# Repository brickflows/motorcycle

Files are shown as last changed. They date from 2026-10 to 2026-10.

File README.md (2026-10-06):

# Café Racer Concept

A complete motorcycle modelled part by part in SolidWorks, with my own bodywork and a frame I redesigned to pass structural analysis in ANSYS, then rendered and cut into a 70-second product film in Blender.

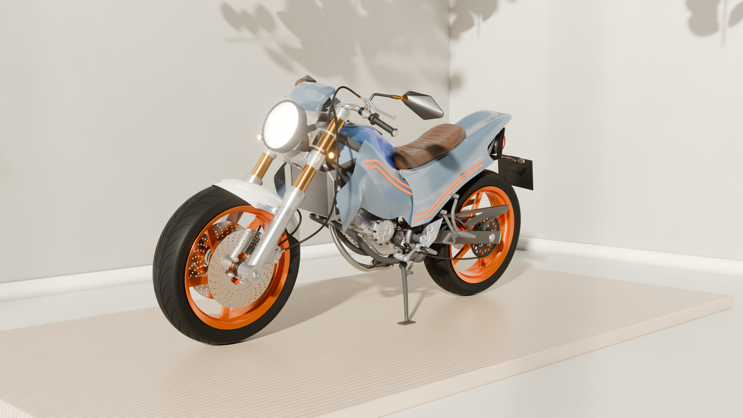
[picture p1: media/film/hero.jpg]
Café Racer Concept: watch the film


**[Watch the film (1080p, 23 MB)](media/film/cafe-racer-concept-1080p.mp4)** or on **[Watch on YouTube](https://www.youtube.com/watch?v=PtR7k8kXTPk)**

| | |
|---|---|
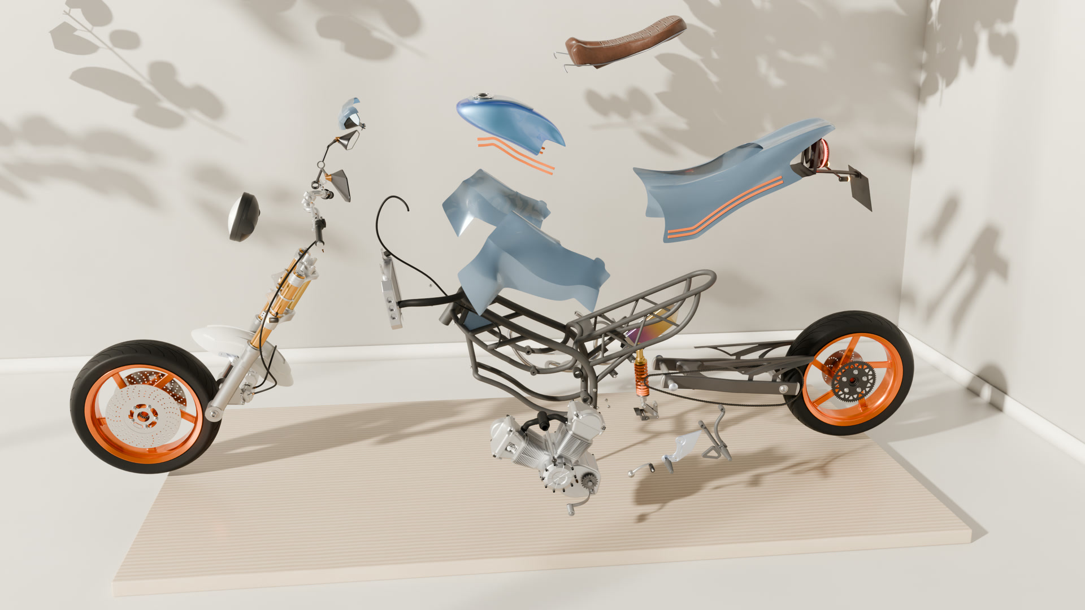
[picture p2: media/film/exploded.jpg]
Exploded view
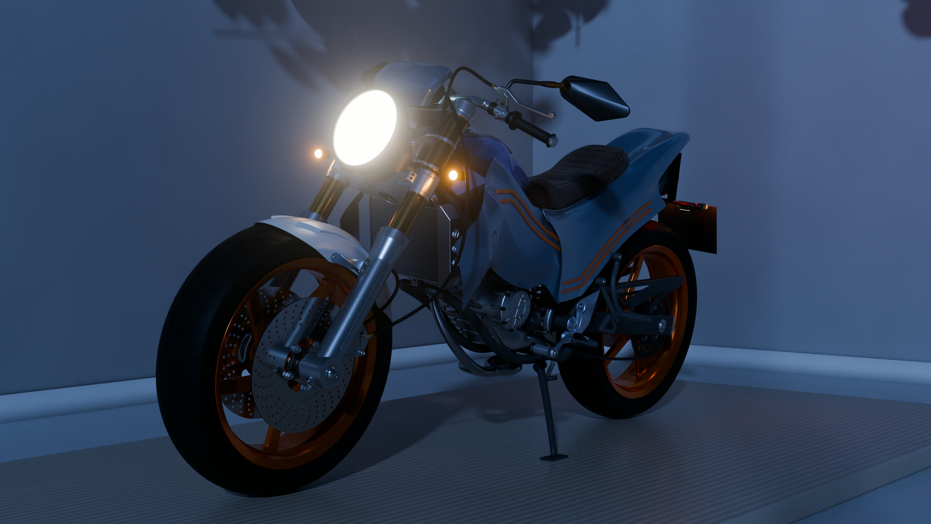
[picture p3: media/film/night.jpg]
Night scene with lights on
|  |  |
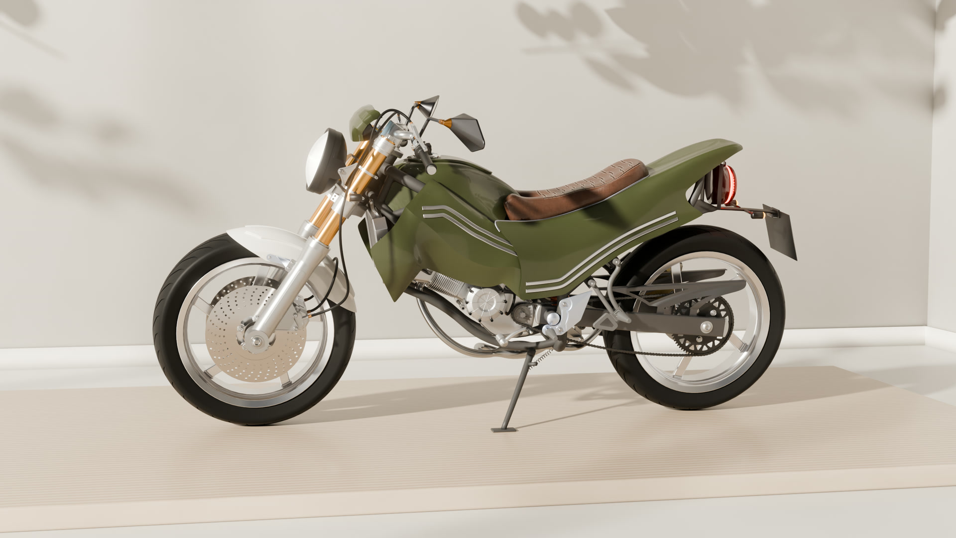
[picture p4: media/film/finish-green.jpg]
Army Green finish
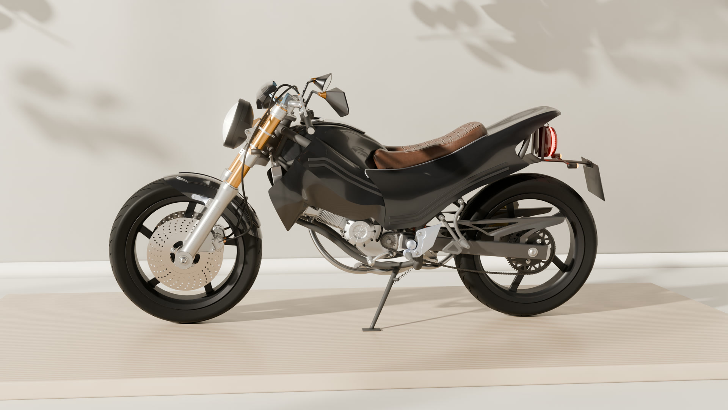
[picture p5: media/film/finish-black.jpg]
Midnight Black finish
|  |  |

## What is in this repo

| Folder | Contents |
|---|---|
| [`cad/`](cad) | SolidWorks source: 217 parts, 41 assemblies and 42 drawings, grouped by subsystem (engine cases, clutch hub, shafts, transmission, wheels, brakes, suspension, lights, bodywork). The top-level assembly is `cad/Assembly/motocycle_assembly1.SLDASM`. |
| [`cad/assembly drawings/`](cad/assembly%20drawings) | Assembly drawings as SolidWorks drawings and PDFs. |
| [`simulation/`](simulation) | Geometry used for the frame and output-shaft FEA, and the stress animations exported from ANSYS Mechanical. |
| [`media/renders/`](media/renders) | Stills of the sub-assemblies: engine, engine head, clutch hub, crankshaft, wheels, shock absorber, hand brake, mirrors, speedometer. |
| [`media/animations/`](media/animations) | The full assembly sequence from SolidWorks and a cam-chain motion study. |
| [`scripts/solidworks/`](scripts/solidworks) | VBA macros that assign materials across the assembly and export every sub-assembly to glTF for Blender. |
| [`scripts/film/`](scripts/film) | Python scripts that check and merge render-farm frames, add the captions and end card in Blender, and build the soundtrack. |
| [`docs/`](docs) | Proposed drawing-number scheme for the project. |

## How it was made

1. **CAD.** Every part was modelled in SolidWorks 2026 and built up through sub-assemblies into one top-level assembly. The bodywork (tank, seat, side and rear panels) is my own design.
2. **Simulation.** The frame was analysed in ANSYS Mechanical and redesigned until it passed. The output shaft was analysed as well.
3. **Export.** A macro walks the assembly tree and exports each sub-assembly to glTF, so the Blender scene keeps the same structure as the CAD.
4. **Rendering.** Materials, lighting and animation were done in Blender 5.2 with Cycles. The 1,620 frames were rendered at 2560x1440 on a render farm.
5. **Edit and sound.** Captions and the end card are added by `scripts/film/make_edit.py`. The soundtrack (music edit, engine and synthesized effects) is built and mastered by `scripts/film/make_audio.py`.

## Opening the CAD

Open `cad/Assembly/motocycle_assembly1.SLDASM` in SolidWorks 2026 or later. Keep the folder structure as it is so the assembly can find its parts.

## Not included

The Blender scene files, the raw ANSYS result files and the glTF exports are left out because of their size. The glTF exports can be regenerated with `scripts/solidworks/motorcycle_export_gltf.bas`.

## Credits

- The project started from the part reference drawings in Christopher Rothera's Udemy course "PTC Creo Parametric - Full Motorbike Build", which I remodelled in SolidWorks. The course material itself is not in this repo.
- The bodywork is my own design, the frame was redesigned to pass structural analysis, and a number of other parts were modified along the way.
- Music: "Hard EDM" by kulakovka, from Pixabay.
- Studio lighting: `studio_small_09` HDRI from Poly Haven. Several materials are from BlenderKit.

## Author

Micheal Adediran, Mechanical Engineering student at the University of Lagos. More work at [mikedoesrobots.com](https://mikedoesrobots.com).

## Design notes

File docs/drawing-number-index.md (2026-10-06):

# Motorcycle Build - Drawing Number Index (PROPOSED)

Generated 2026-09-03 from `C:\Users\micheal\Downloads\motorcyle`. **Planning pass only - nothing on disk was renamed or modified.**

- **192 documents**: 168 parts, 21 assemblies, 3 drawings

- **Scheme**: `MC-[TYPE]-[SEQ]`, SEQ zero-padded to 3 and incrementing per TYPE across the whole project, not per folder.

- **Sequencing basis**: file **creation date** (ascending), tie-broken alphabetically. See the caveat under *Sequencing* below.

- **Numbers are assigned to models.** A `.SLDDRW` inherits the number of the part or assembly it documents, so `foo.SLDPRT` and `foo.SLDDRW` share one DWG NO. rather than burning two.

## Type codes

Codes from your brief: `GER` `SFT` `HUB` `BRK` `PLT` `FRM`. `BRK` is unused - no bracket-type part appears in the project.

| Code | Meaning | Count |
|---|---|---|
| `ARM` | Arm | 11 |
| `ASM` | Assembly | 21 |
| `BAR` | Handlebar | 1 |
| `BAS` | Base | 1 |
| `BDG` | Bridge | 3 |
| `BDY` | Body | 4 |
| `BLB` | Bulb | 5 |
| `BLT` | Bolt / Screw | 17 |
| `BRG` | Bearing (incl. rings & balls) | 7 |
| `BSH` | Bushing | 3 |
| `CAP` | Cap | 2 |
| `CHN` | Chain Link | 4 |
| `CON` | Connector | 2 |
| `CSE` | Case / Housing | 12 |
| `DRM` | Drum | 1 |
| `FRM` | Frame Member | 7 |
| `GER` | Gear | 12 |
| `GRD` | Guard | 4 |
| `GRP` | Grip | 1 |
| `HUB` | Hub / Basket | 2 |
| `LNR` | Liner | 1 |
| `LVR` | Lever | 1 |
| `MAG` | Magnet | 1 |
| `MAN` | Manifold | 1 |
| `MIR` | Mirror | 1 |
| `MUF` | Muffler Section | 2 |
| `NUT` | Nut | 2 |
| `PIN` | Pin | 13 |
| `PIP` | Pipe | 3 |
| `PLG` | Plug | 4 |
| `PLT` | Plate | 7 |
| `PST` | Piston | 1 |
| `RAT` | Ratchet | 2 |
| `RIM` | Rim | 1 |
| `ROD` | Rod | 2 |
| `ROL` | Roller | 1 |
| `RST` | Foot Rest | 1 |
| `SCR` | Screen | 1 |
| `SFT` | Shaft | 11 |
| `SHK` | Shock Absorber Section | 2 |
| `SPK` | Sprocket | 4 |
| `SPR` | Spring | 3 |
| `TYR` | Tyre | 1 |
| `UNK` | UNCLASSIFIED | 2 |
| `VLV` | Valve | 1 |

## Proposed numbering

Sorted by folder to match the structure on disk.

| Current Filename | Folder | Inferred Type | Proposed DWG NO. | Proposed Title | Notes/Flags |
|---|---|---|---|---|---|
| `frame.SLDPRT` | `frame\01_Introduction - Motorcycle Frame` | FRM (Part) | **MC-FRM-001** | Motorcycle Main Frame | No drawing yet. |
| `left-side-engine-case.SLDPRT` | `frame\02_Left Side Engine Case` | CSE (Part) | **MC-CSE-001** | Left Side Engine Case | No drawing yet. |
| `right-side-engine-case.SLDDRW` | `frame\03_Right Side Engine Case` | CSE (Drawing) | **MC-CSE-002** | Right Side Engine Case | Drawing of the model above - inherits its number. Macro can write to this today. |
| `right-side-engine-case.SLDPRT` | `frame\03_Right Side Engine Case` | CSE (Part) | **MC-CSE-002** | Right Side Engine Case | **Drawing exists** - macro can write to it today. |
| `basket_gear_mced.SLDDRW` | `frame\04_Clutch Hub Parts` | GER (Drawing) | **MC-GER-001** | Basket Gear | Drawing of the model above - inherits its number. Macro can write to this today. |
| `basket_gear_mced.SLDPRT` | `frame\04_Clutch Hub Parts` | GER (Part) | **MC-GER-001** | Basket Gear | **Drawing exists** - macro can write to it today. |
| `clutch-hub-shaft-nut.SLDPRT` | `frame\04_Clutch Hub Parts` | NUT (Part) | **MC-NUT-002** | Clutch Hub Shaft Nut | No drawing yet. |
| `clutch-hub-steel-plate.SLDPRT` | `frame\04_Clutch Hub Parts` | PLT (Part) | **MC-PLT-007** | Clutch Hub Steel Plate | No drawing yet. |
| `clutch_hub_basket_mced.SLDDRW` | `frame\04_Clutch Hub Parts` | HUB (Drawing) | **MC-HUB-002** | Clutch Hub Basket | Drawing of the model above - inherits its number. Macro can write to this today. |
| `clutch_hub_basket_mced.SLDPRT` | `frame\04_Clutch Hub Parts` | HUB (Part) | **MC-HUB-002** | Clutch Hub Basket | **Drawing exists** - macro can write to it today. |
| `clutch_hub_friction_plate.SLDPRT` | `frame\04_Clutch Hub Parts` | PLT (Part) | **MC-PLT-001** | Clutch Hub Friction Plate | No drawing yet. |
| `clutch_hub_gear_bearing.SLDPRT` | `frame\04_Clutch Hub Parts` | BRG (Part) | **MC-BRG-001** | Clutch Hub Gear Bearing | Typed by noun head (`bearing`), not the `gear` in the name. No drawing yet. |
| `clutch_hub_gear_pin.SLDPRT` | `frame\04_Clutch Hub Parts` | PIN (Part) | **MC-PIN-001** | Clutch Hub Gear Pin | Typed by noun head (`pin`), not the `gear` in the name. No drawing yet. |
| `clutch_hub_gear_plate.SLDPRT` | `frame\04_Clutch Hub Parts` | PLT (Part) | **MC-PLT-002** | Clutch Hub Gear Plate | Typed by noun head (`plate`), not the `gear` in the name. No drawing yet. |
| `clutch_hub_inner_hub.SLDPRT` | `frame\04_Clutch Hub Parts` | HUB (Part) | **MC-HUB-001** | Clutch Hub Inner Hub | No drawing yet. |
| `clutch_hub_pressure_bolt.SLDPRT` | `frame\04_Clutch Hub Parts` | BLT (Part) | **MC-BLT-001** | Clutch Hub Pressure Bolt | No drawing yet. |
| `clutch_hub_pressure_plate.SLDPRT` | `frame\04_Clutch Hub Parts` | PLT (Part) | **MC-PLT-003** | Clutch Hub Pressure Plate | No drawing yet. |
| `clutch_hub_pressure_shaft.SLDPRT` | `frame\04_Clutch Hub Parts` | SFT (Part) | **MC-SFT-001** | Clutch Hub Pressure Shaft | No drawing yet. |
| `clutch_hub_pressure_spring.SLDPRT` | `frame\04_Clutch Hub Parts` | SPR (Part) | **MC-SPR-001** | Clutch Hub Pressure Spring | No drawing yet. |
| `clutch_hub_engine_case_mced.SLDPRT` | `frame\05_Clutch Hub Engine Case` | CSE (Part) | **MC-CSE-003** | Clutch Hub Engine Case | No drawing yet. |
| `input_shaft.SLDPRT` | `frame\06_Input Shaft Parts` | SFT (Part) | **MC-SFT-002** | Input Shaft | No drawing yet. |
| `input_shaft_gear_five.SLDPRT` | `frame\06_Input Shaft Parts` | GER (Part) | **MC-GER-002** | Input Shaft Gear Five | No drawing yet. |
| `input_shaft_gear_four.SLDPRT` | `frame\06_Input Shaft Parts` | GER (Part) | **MC-GER-003** | Input Shaft Gear Four | No drawing yet. |
| `input_shaft_gear_one.SLDPRT` | `frame\06_Input Shaft Parts` | GER (Part) | **MC-GER-005** | Input Shaft Gear One | No drawing yet. |
| `input_shaft_gear_three.SLDPRT` | `frame\06_Input Shaft Parts` | GER (Part) | **MC-GER-006** | Input Shaft Gear Three | No drawing yet. |
| `input_shaft_gear_two.SLDPRT` | `frame\06_Input Shaft Parts` | GER (Part) | **MC-GER-004** | Input Shaft Gear Two | No drawing yet. |
| `output_shaft.SLDPRT` | `frame\07_Output Shaft Parts` | SFT (Part) | **MC-SFT-003** | Output Shaft | No drawing yet. |
| `output_shaft_gear_five.SLDPRT` | `frame\07_Output Shaft Parts` | GER (Part) | **MC-GER-009** | Output Shaft Gear Five | No drawing yet. |
| `output_shaft_gear_four.SLDPRT` | `frame\07_Output Shaft Parts` | GER (Part) | **MC-GER-010** | Output Shaft Gear Four | No drawing yet. |
| `output_shaft_gear_one.SLDPRT` | `frame\07_Output Shaft Parts` | GER (Part) | **MC-GER-007** | Output Shaft Gear One | No drawing yet. |
| `output_shaft_gear_three.SLDPRT` | `frame\07_Output Shaft Parts` | GER (Part) | **MC-GER-008** | Output Shaft Gear Three | No drawing yet. |
| `output_shaft_gear_two.SLDPRT` | `frame\07_Output Shaft Parts` | GER (Part) | **MC-GER-011** | Output Shaft Gear Two | No drawing yet. |
| `output_shaft_sprocket.SLDPRT` | `frame\07_Output Shaft Parts` | SPK (Part) | **MC-SPK-001** | Output Shaft Sprocket | No drawing yet. |
| `crank_shaft.SLDPRT` | `frame\08_Crank Shaft Parts` | SFT (Part) | **MC-SFT-004** | Crank Shaft | No drawing yet. |
| `crank_shaft_gear_one.SLDPRT` | `frame\08_Crank Shaft Parts` | GER (Part) | **MC-GER-012** | Crank Shaft Gear One | No drawing yet. |
| `crank_shaft_sprocket.SLDPRT` | `frame\08_Crank Shaft Parts` | SPK (Part) | **MC-SPK-002** | Crank Shaft Sprocket | No drawing yet. |
| `stator_case.SLDPRT` | `frame\09_Stator Parts` | CSE (Part) | **MC-CSE-004** | Stator Case | No drawing yet. |
| `stator_engine_case.SLDPRT` | `frame\09_Stator Parts` | CSE (Part) | **MC-CSE-005** | Stator Engine Case | No drawing yet. |
| `stator_magnets.SLDPRT` | `frame\09_Stator Parts` | MAG (Part) | **MC-MAG-001** | Stator Magnets | No drawing yet. |
| `stator_nut.SLDPRT` | `frame\09_Stator Parts` | NUT (Part) | **MC-NUT-001** | Stator Nut | No drawing yet. |
| `shift_drum.SLDPRT` | `frame\10_Shift Drum Parts` | DRM (Part) | **MC-DRM-001** | Shift Drum | No drawing yet. |
| `shift_drum_gear_arms_pin.SLDPRT` | `frame\10_Shift Drum Parts` | PIN (Part) | **MC-PIN-002** | Shift Drum Gear Arms Pin | No drawing yet. |
| `shift_drum_placer_arm.SLDPRT` | `frame\10_Shift Drum Parts` | ARM (Part) | **MC-ARM-004** | Shift Drum Placer Arm | No drawing yet. |
| `shift_drum_ratchet_arm.SLDPRT` | `frame\10_Shift Drum Parts` | ARM (Part) | **MC-ARM-001** | Shift Drum Ratchet Arm | No drawing yet. |
| `shift_drum_transmission_arm.SLDPRT` | `frame\10_Shift Drum Parts` | ARM (Part) | **MC-ARM-002** | Shift Drum Transmission Arm | No drawing yet. |
| `shift_drum_transmission_arm_two.SLDPRT` | `frame\10_Shift Drum Parts` | ARM (Part) | **MC-ARM-003** | Shift Drum Transmission Arm Two | No drawing yet. |
| `transmission-shaft-foot-roller.SLDPRT` | `frame\11_Transmission Parts` | ROL (Part) | **MC-ROL-001** | Transmission Shaft Foot Roller | No drawing yet. |
| `transmission-shaft.SLDPRT` | `frame\11_Transmission Parts` | SFT (Part) | **MC-SFT-011** | Transmission Shaft | No drawing yet. |
| `transmission_pedal_plug.SLDPRT` | `frame\11_Transmission Parts` | PLG (Part) | **MC-PLG-001** | Transmission Pedal Plug | No drawing yet. |
| `transmission_ratchet_a.SLDPRT` | `frame\11_Transmission Parts` | RAT (Part) | **MC-RAT-001** | Transmission Ratchet A | No drawing yet. |
| `transmission_ratchet_b.SLDPRT` | `frame\11_Transmission Parts` | RAT (Part) | **MC-RAT-002** | Transmission Ratchet B | No drawing yet. |
| `cylinder_section_engine_case.SLDPRT` | `frame\12_Cylinder Section Engine Case and Engine Head Case` | CSE (Part) | **MC-CSE-007** | Cylinder Section Engine Case | No drawing yet. |
| `engine_head_case.SLDPRT` | `frame\12_Cylinder Section Engine Case and Engine Head Case` | CSE (Part) | **MC-CSE-006** | Engine Head Case | No drawing yet. |
| `valve-spring.SLDPRT` | `frame\13_Valve Section Engine Case and Valve Parts` | SPR (Part) | **MC-SPR-003** | Valve Spring | No drawing yet. |
| `valve.SLDPRT` | `frame\13_Valve Section Engine Case and Valve Parts` | VLV (Part) | **MC-VLV-001** | Valve | No drawing yet. |
| `valve_section_engine_case.SLDPRT` | `frame\13_Valve Section Engine Case and Valve Parts` | CSE (Part) | **MC-CSE-008** | Valve Section Engine Case | No drawing yet. |
| `Spark Plug.SLDPRT` | `frame\14-Spark Plugs` | PLG (Part) | **MC-PLG-004** | Spark Plug | No drawing yet. |
| `rocker_arm.SLDPRT` | `frame\15_Rocker Arm Parts` | ARM (Part) | **MC-ARM-005** | Rocker Arm | No drawing yet. |
| `rocker_shaft.SLDPRT` | `frame\15_Rocker Arm Parts` | SFT (Part) | **MC-SFT-005** | Rocker Shaft | No drawing yet. |
| `piston.SLDPRT` | `frame\16_Piston Parts` | PST (Part) | **MC-PST-001** | Piston | No drawing yet. |
| `piston_bolt.SLDPRT` | `frame\16_Piston Parts` | BLT (Part) | **MC-BLT-002** | Piston Bolt | No drawing yet. |
| `piston_bushing_Eng_Drw.SLDPRT` | `frame\16_Piston Parts` | BSH (Part) | **MC-BSH-001** | Piston Bushing | **FLAG** - `Eng_Drw` suffix is unusual; confirm it is the production part. No drawing yet. |
| `piston_pin.SLDPRT` | `frame\16_Piston Parts` | PIN (Part) | **MC-PIN-003** | Piston Pin | No drawing yet. |
| `piston_pin_plug.SLDPRT` | `frame\16_Piston Parts` | PLG (Part) | **MC-PLG-002** | Piston Pin Plug | No drawing yet. |
| `cam_chain_inner_mced.SLDPRT` | `frame\17_Cam Chain Parts` | CHN (Part) | **MC-CHN-001** | Cam Chain Inner | No drawing yet. |
| `cam_chain_outer_mced.SLDPRT` | `frame\17_Cam Chain Parts` | CHN (Part) | **MC-CHN-002** | Cam Chain Outer | No drawing yet. |
| `cam_shaft_bushing_mced.SLDPRT` | `frame\17_Cam Chain Parts` | BSH (Part) | **MC-BSH-002** | Cam Shaft Bushing | No drawing yet. |
| `cam_shaft_mced.SLDPRT` | `frame\17_Cam Chain Parts` | SFT (Part) | **MC-SFT-006** | Cam Shaft | No drawing yet. |
| `cam_shaft_sprocket_mced.SLDPRT` | `frame\17_Cam Chain Parts` | SPK (Part) | **MC-SPK-003** | Cam Shaft Sprocket | No drawing yet. |
| `articulated_rod_lower_mced.SLDPRT` | `frame\18_Articulated Rod Upper and Lower` | ROD (Part) | **MC-ROD-002** | Articulated Rod Lower | No drawing yet. |
| `articulated_rod_upper_mced.SLDPRT` | `frame\18_Articulated Rod Upper and Lower` | ROD (Part) | **MC-ROD-001** | Articulated Rod Upper | No drawing yet. |
| `20mm_bearing.SLDASM` | `frame\19_20mm and 30mm Ball Bearings` | ASM (Assembly) | **MC-ASM-012** | 20mm Bearing | No drawing yet. |
| `20mm_bearing_balls_mced.SLDPRT` | `frame\19_20mm and 30mm Ball Bearings` | BRG (Part) | **MC-BRG-007** | 20mm Bearing Balls | No drawing yet. |
| `20mm_bearing_inner_ring_mced.SLDPRT` | `frame\19_20mm and 30mm Ball Bearings` | BRG (Part) | **MC-BRG-005** | 20mm Bearing Inner Ring | No drawing yet. |
| `20mm_bearing_outer_ring_mced.SLDPRT` | `frame\19_20mm and 30mm Ball Bearings` | BRG (Part) | **MC-BRG-002** | 20mm Bearing Outer Ring | No drawing yet. |
| `30mm_bearing.SLDASM` | `frame\19_20mm and 30mm Ball Bearings` | ASM (Assembly) | **MC-ASM-017** | 30mm Bearing | No drawing yet. |
| `30mm_bearing_balls_mced.SLDPRT` | `frame\19_20mm and 30mm Ball Bearings` | BRG (Part) | **MC-BRG-003** | 30mm Bearing Balls | No drawing yet. |
| `30mm_bearing_inner_ring_mced.SLDPRT` | `frame\19_20mm and 30mm Ball Bearings` | BRG (Part) | **MC-BRG-004** | 30mm Bearing Inner Ring | No drawing yet. |
| `30mm_bearing_outer_ring_mced.SLDPRT` | `frame\19_20mm and 30mm Ball Bearings` | BRG (Part) | **MC-BRG-006** | 30mm Bearing Outer Ring | No drawing yet. |
| `bolt_cylinder_section_mced.SLDPRT` | `frame\20_Bolts - Various` | BLT (Part) | **MC-BLT-010** | Bolt Cylinder Section | No drawing yet. |
| `bolt_engine_case_l_to_c_mced.SLDPRT` | `frame\20_Bolts - Various` | BLT (Part) | **MC-BLT-009** | Bolt Engine Case L To C | No drawing yet. |
| `bolt_engine_case_l_to_r_mced.SLDPRT` | `frame\20_Bolts - Various` | BLT (Part) | **MC-BLT-008** | Bolt Engine Case L To R | No drawing yet. |
| `bolt_front_wheel_frame_clamp_mced.SLDPRT` | `frame\20_Bolts - Various` | BLT (Part) | **MC-BLT-007** | Bolt Front Wheel Frame Clamp | No drawing yet. |
| `bolt_head_case_mced.SLDPRT` | `frame\20_Bolts - Various` | BLT (Part) | **MC-BLT-006** | Bolt Head Case | No drawing yet. |
| `bolt_large_engine_case_l_to_r_mced.SLDPRT` | `frame\20_Bolts - Various` | BLT (Part) | **MC-BLT-005** | Bolt Large Engine Case L To R | No drawing yet. |
| `frame_engine_bolt.SLDPRT` | `frame\20_Bolts - Various` | BLT (Part) | **MC-BLT-004** | Frame Engine Bolt | No drawing yet. |
| `testscrew.SLDPRT` | `frame\20_Bolts - Various` | BLT (Part) | **MC-BLT-003** | Test Screw | **FLAG** - looks like a throwaway test file. Confirm it belongs in the release set. No drawing yet. |
| `wheel_rim.SLDPRT` | `frame\21_Wheel Rim` | RIM (Part) | **MC-RIM-001** | Wheel Rim | No drawing yet. |
| `tyre.SLDPRT` | `frame\22_Tyre` | TYR (Part) | **MC-TYR-001** | Tyre | No drawing yet. |
| `rear_wheel_brake_plate.SLDPRT` | `frame\23_Rear Wheel Parts` | PLT (Part) | **MC-PLT-004** | Rear Wheel Brake Plate | No drawing yet. |
| `rear_wheel_frame.SLDPRT` | `frame\23_Rear Wheel Parts` | FRM (Part) | **MC-FRM-002** | Rear Wheel Frame | No drawing yet. |
| `rear_wheel_frame_18mm.SLDPRT` | `frame\23_Rear Wheel Parts` | FRM (Part) | **MC-FRM-007** | Rear Wheel Frame 18mm | **FLAG** - size variant of `rear_wheel_frame`; may be an alternate config rather than a distinct drawing. No drawing yet. |
| `rear_wheel_frame_absorber_shaft.SLDPRT` | `frame\23_Rear Wheel Parts` | SFT (Part) | **MC-SFT-009** | Rear Wheel Frame Absorber Shaft | No drawing yet. |
| `rear_wheel_frame_as_bolt.SLDPRT` | `frame\23_Rear Wheel Parts` | BLT (Part) | **MC-BLT-013** | Rear Wheel Frame As Bolt | **FLAG** - `as` is unclear (absorber shaft?). Title is a guess. No drawing yet. |
| `rear_wheel_frame_c_shaft_plug.SLDPRT` | `frame\23_Rear Wheel Parts` | PLG (Part) | **MC-PLG-003** | Rear Wheel Frame C Shaft Plug | No drawing yet. |
| `rear_wheel_frame_connector_shaf.SLDPRT` | `frame\23_Rear Wheel Parts` | SFT (Part) | **MC-SFT-008** | Rear Wheel Frame Connector Shaf | **FLAG** - filename appears truncated (`shaf` -> `shaft`). Do NOT rename; noted only. No drawing yet. |
| `rear_wheel_frame_end_cap.SLDPRT` | `frame\23_Rear Wheel Parts` | CAP (Part) | **MC-CAP-001** | Rear Wheel Frame End Cap | No drawing yet. |
| `rear_wheel_frame_old.SLDPRT` | `frame\23_Rear Wheel Parts` | FRM (Part) | **MC-FRM-006** | Rear Wheel Frame Old | **FLAG** - `_old` suggests superseded by `rear_wheel_frame`. Confirm before numbering. No drawing yet. |
| `rear_wheel_frame_shaft.SLDPRT` | `frame\23_Rear Wheel Parts` | SFT (Part) | **MC-SFT-007** | Rear Wheel Frame Shaft | No drawing yet. |
| `rear_wheel_frame_shaft_bolt.SLDPRT` | `frame\23_Rear Wheel Parts` | BLT (Part) | **MC-BLT-012** | Rear Wheel Frame Shaft Bolt | No drawing yet. |
| `rear_wheel_sprocket.SLDPRT` | `frame\23_Rear Wheel Parts` | SPK (Part) | **MC-SPK-004** | Rear Wheel Sprocket | No drawing yet. |
| `rear_wheel_sprocket_bolt.SLDPRT` | `frame\23_Rear Wheel Parts` | BLT (Part) | **MC-BLT-011** | Rear Wheel Sprocket Bolt | No drawing yet. |
| `front_wheel_brake_plate.SLDPRT` | `frame\24_Front Wheel Parts` | PLT (Part) | **MC-PLT-006** | Front Wheel Brake Plate | No drawing yet. |
| `front_wheel_brake_plate_left.SLDPRT` | `frame\24_Front Wheel Parts` | PLT (Part) | **MC-PLT-005** | Front Wheel Brake Plate Left | No drawing yet. |
| `front_wheel_frame_shaft_bolt.SLDPRT` | `frame\24_Front Wheel Parts` | BLT (Part) | **MC-BLT-015** | Front Wheel Frame Shaft Bolt | No drawing yet. |
| `front_wheel_frame_shaft_boltdd.SLDPRT` | `frame\24_Front Wheel Parts` | BLT (Part) | **MC-BLT-016** | Front Wheel Frame Shaft Bolt (dd) | **FLAG** - `dd` suffix suggests a stray duplicate of `front_wheel_frame_shaft_bolt`. No drawing yet. |
| `front_wheel_guard.SLDPRT` | `frame\24_Front Wheel Parts` | GRD (Part) | **MC-GRD-001** | Front Wheel Guard | No drawing yet. |
| `front_wheel_guard_bridge.SLDPRT` | `frame\24_Front Wheel Parts` | BDG (Part) | **MC-BDG-001** | Front Wheel Guard Bridge | No drawing yet. |
| `front_wheel_guard_bridge_pin_a.SLDPRT` | `frame\24_Front Wheel Parts` | PIN (Part) | **MC-PIN-005** | Front Wheel Guard Bridge Pin A | No drawing yet. |
| `front_wheel_guard_bridge_pin_b.SLDPRT` | `frame\24_Front Wheel Parts` | PIN (Part) | **MC-PIN-004** | Front Wheel Guard Bridge Pin B | No drawing yet. |
| `front_wheel_lower_connector_arm.SLDPRT` | `frame\24_Front Wheel Parts` | ARM (Part) | **MC-ARM-007** | Front Wheel Lower Connector Arm | No drawing yet. |
| `front_wheel_m_frame_inner_pipe.SLDPRT` | `frame\24_Front Wheel Parts` | PIP (Part) | **MC-PIP-002** | Front Wheel M Frame Inner Pipe | No drawing yet. |
| `front_wheel_shaft.SLDPRT` | `frame\24_Front Wheel Parts` | SFT (Part) | **MC-SFT-010** | Front Wheel Shaft | No drawing yet. |
| `front_wheel_side_base_pipe.SLDPRT` | `frame\24_Front Wheel Parts` | PIP (Part) | **MC-PIP-003** | Front Wheel Side Base Pipe | No drawing yet. |
| `front_wheel_side_pipe.SLDPRT` | `frame\24_Front Wheel Parts` | PIP (Part) | **MC-PIP-001** | Front Wheel Side Pipe | No drawing yet. |
| `front_wheel_side_pipe_top_bolt.SLDPRT` | `frame\24_Front Wheel Parts` | BLT (Part) | **MC-BLT-014** | Front Wheel Side Pipe Top Bolt | No drawing yet. |
| `front_wheel_upper_connector_arm.SLDPRT` | `frame\24_Front Wheel Parts` | ARM (Part) | **MC-ARM-006** | Front Wheel Upper Connector Arm | No drawing yet. |
| `front_wheel_brake_body.SLDPRT` | `frame\25_Front Wheel Brake Body and Mirror` | BDY (Part) | **MC-BDY-001** | Front Wheel Brake Body | No drawing yet. |
| `front_wheel_brake_body_mirror.SLDPRT` | `frame\25_Front Wheel Brake Body and Mirror` | MIR (Part) | **MC-MIR-001** | Front Wheel Brake Body Mirror | No drawing yet. |
| `foot_rest.SLDPRT` | `frame\26_Foot Rest Parts` | RST (Part) | **MC-RST-001** | Foot Rest | No drawing yet. |
| `foot_rest_kick_guard.SLDPRT` | `frame\26_Foot Rest Parts` | GRD (Part) | **MC-GRD-003** | Foot Rest Kick Guard | No drawing yet. |
| `foot_rest_pin.SLDPRT` | `frame\26_Foot Rest Parts` | PIN (Part) | **MC-PIN-012** | Foot Rest Pin | No drawing yet. |
| `rear_foot_rest_frame.SLDPRT` | `frame\26_Foot Rest Parts` | FRM (Part) | **MC-FRM-003** | Rear Foot Rest Frame | No drawing yet. |
| `exhaust_muffler_guard.SLDPRT` | `frame\27_Exhaust Parts` | GRD (Part) | **MC-GRD-002** | Exhaust Muffler Guard | No drawing yet. |
| `exhaust_muffler_mid_section.SLDPRT` | `frame\27_Exhaust Parts` | MUF (Part) | **MC-MUF-001** | Exhaust Muffler Mid Section | No drawing yet. |
| `exhaust_muffler_upper_section.SLDPRT` | `frame\27_Exhaust Parts` | MUF (Part) | **MC-MUF-002** | Exhaust Muffler Upper Section | No drawing yet. |
| `air_intake_grill_body_mced.SLDPRT` | `frame\29_Air Intake Front Grill Body and Cap` | BDY (Part) | **MC-BDY-004** | Air Intake Grill Body | No drawing yet. |
| `air_intake_grill_cap_mced.SLDPRT` | `frame\29_Air Intake Front Grill Body and Cap` | CAP (Part) | **MC-CAP-002** | Air Intake Grill Cap | No drawing yet. |
| `shock_absorber_arm_pin_a.SLDPRT` | `frame\30_Shock Absorber Parts` | PIN (Part) | **MC-PIN-010** | Shock Absorber Arm Pin A | No drawing yet. |
| `shock_absorber_arm_pin_b.SLDPRT` | `frame\30_Shock Absorber Parts` | PIN (Part) | **MC-PIN-007** | Shock Absorber Arm Pin B | No drawing yet. |
| `shock_absorber_arm_pin_c.SLDPRT` | `frame\30_Shock Absorber Parts` | PIN (Part) | **MC-PIN-008** | Shock Absorber Arm Pin C | No drawing yet. |
| `shock_absorber_arm_pin_d.SLDPRT` | `frame\30_Shock Absorber Parts` | PIN (Part) | **MC-PIN-009** | Shock Absorber Arm Pin D | No drawing yet. |
| `shock_absorber_bushing.SLDPRT` | `frame\30_Shock Absorber Parts` | BSH (Part) | **MC-BSH-003** | Shock Absorber Bushing | No drawing yet. |
| `shock_absorber_connector_arm.SLDPRT` | `frame\30_Shock Absorber Parts` | ARM (Part) | **MC-ARM-010** | Shock Absorber Connector Arm | No drawing yet. |
| `shock_absorber_frame_arm.SLDPRT` | `frame\30_Shock Absorber Parts` | ARM (Part) | **MC-ARM-009** | Shock Absorber Frame Arm | No drawing yet. |
| `shock_absorber_inner_section.SLDPRT` | `frame\30_Shock Absorber Parts` | SHK (Part) | **MC-SHK-002** | Shock Absorber Inner Section | No drawing yet. |
| `shock_absorber_outer_section.SLDPRT` | `frame\30_Shock Absorber Parts` | SHK (Part) | **MC-SHK-001** | Shock Absorber Outer Section | No drawing yet. |
| `shock_absorber_pin_a_bolt.SLDPRT` | `frame\30_Shock Absorber Parts` | BLT (Part) | **MC-BLT-017** | Shock Absorber Pin A Bolt | No drawing yet. |
| `shock_absorber_spring.SLDPRT` | `frame\30_Shock Absorber Parts` | SPR (Part) | **MC-SPR-002** | Shock Absorber Spring | No drawing yet. |
| `hand_brake_body.SLDPRT` | `frame\31_Handlebar and Hand Brake Parts` | BDY (Part) | **MC-BDY-002** | Hand Brake Body | No drawing yet. |
| `hand_brake_cable_connector.SLDPRT` | `frame\31_Handlebar and Hand Brake Parts` | CON (Part) | **MC-CON-001** | Hand Brake Cable Connector | No drawing yet. |
| `hand_brake_handlebar_bridge.SLDPRT` | `frame\31_Handlebar and Hand Brake Parts` | BDG (Part) | **MC-BDG-003** | Hand Brake Handlebar Bridge | No drawing yet. |
| `hand_brake_lever.SLDPRT` | `frame\31_Handlebar and Hand Brake Parts` | LVR (Part) | **MC-LVR-001** | Hand Brake Lever | No drawing yet. |
| `hand_brake_pin.SLDPRT` | `frame\31_Handlebar and Hand Brake Parts` | PIN (Part) | **MC-PIN-006** | Hand Brake Pin | No drawing yet. |
| `handle_bar.SLDPRT` | `frame\31_Handlebar and Hand Brake Parts` | BAR (Part) | **MC-BAR-001** | Handlebar | No drawing yet. |
| `handle_bar_connector_arm_bridge.SLDPRT` | `frame\31_Handlebar and Hand Brake Parts` | BDG (Part) | **MC-BDG-002** | Handle Bar Connector Arm Bridge | No drawing yet. |
| `handle_bar_connector_bridge_pin.SLDPRT` | `frame\31_Handlebar and Hand Brake Parts` | PIN (Part) | **MC-PIN-011** | Handle Bar Connector Bridge Pin | No drawing yet. |
| `handle_bar_grip.SLDPRT` | `frame\31_Handlebar and Hand Brake Parts` | GRP (Part) | **MC-GRP-001** | Handle Bar Grip | No drawing yet. |
| `headlight_back_case.SLDPRT` | `frame\32_Headlight Parts` | CSE (Part) | **MC-CSE-010** | Headlight Back Case | No drawing yet. |
| `headlight_bulb.SLDPRT` | `frame\32_Headlight Parts` | BLB (Part) | **MC-BLB-003** | Headlight Bulb | No drawing yet. |
| `headlight_bulb_reflective_liner.SLDPRT` | `frame\32_Headlight Parts` | LNR (Part) | **MC-LNR-001** | Headlight Bulb Reflective Liner | No drawing yet. |
| `headlight_connector_arm.SLDPRT` | `frame\32_Headlight Parts` | ARM (Part) | **MC-ARM-008** | Headlight Connector Arm | No drawing yet. |
| `headlight_front_case.SLDPRT` | `frame\32_Headlight Parts` | CSE (Part) | **MC-CSE-009** | Headlight Front Case | No drawing yet. |
| `headlight_lightbulb.SLDPRT` | `frame\32_Headlight Parts` | BLB (Part) | **MC-BLB-002** | Headlight Lightbulb | No drawing yet. |
| `headlight_lightbulb_back.SLDPRT` | `frame\32_Headlight Parts` | BLB (Part) | **MC-BLB-001** | Headlight Lightbulb Back | No drawing yet. |
| `light-frame-pin.SLDPRT` | `frame\33-Light Frame Pin` | PIN (Part) | **MC-PIN-013** | Light Frame Pin | No drawing yet. |
| `rear-light-case-bulb.SLDPRT` | `frame\34 - Rear Light Parts` | BLB (Part) | **MC-BLB-005** | Rear Light Case Bulb | No drawing yet. |
| `rear-light-frame.SLDPRT` | `frame\34 - Rear Light Parts` | FRM (Part) | **MC-FRM-005** | Rear Light Frame | No drawing yet. |
| `rear-light-front-case.SLDPRT` | `frame\34 - Rear Light Parts` | CSE (Part) | **MC-CSE-012** | Rear Light Front Case | No drawing yet. |
| `rear-light-inner-bulb.SLDPRT` | `frame\34 - Rear Light Parts` | BLB (Part) | **MC-BLB-004** | Rear Light Inner Bulb | No drawing yet. |
| `rear-light-upper-frame.SLDPRT` | `frame\34 - Rear Light Parts` | FRM (Part) | **MC-FRM-004** | Rear Light Upper Frame | No drawing yet. |
| `rear-lightbulb-base.SLDPRT` | `frame\34 - Rear Light Parts` | BAS (Part) | **MC-BAS-001** | Rear Lightbulb Base | No drawing yet. |
| `speedometer-body.SLDPRT` | `frame\35-Speedometer` | BDY (Part) | **MC-BDY-003** | Speedometer Body | No drawing yet. |
| `speedometer-screen.SLDPRT` | `frame\35-Speedometer` | SCR (Part) | **MC-SCR-001** | Speedometer Screen | No drawing yet. |
| `wing-mirror-arm.SLDPRT` | `frame\36- Wing mirror parts` | ARM (Part) | **MC-ARM-011** | Wing Mirror Arm | No drawing yet. |
| `wing-mirror-case.SLDPRT` | `frame\36- Wing mirror parts` | CSE (Part) | **MC-CSE-011** | Wing Mirror Case | No drawing yet. |
| `wing-mirror-connector.SLDPRT` | `frame\36- Wing mirror parts` | CON (Part) | **MC-CON-002** | Wing Mirror Connector | No drawing yet. |
| `assemblyenginecase.SLDASM` | `frame\43_Engine Assembly` | ASM (Assembly) | **MC-ASM-001** | Assemblyenginecase | **FLAG** - near-duplicate of `assemblyenginecaseuse`. Confirm which is current. No drawing yet. |
| `assemblyenginecaseuse.SLDASM` | `frame\43_Engine Assembly` | ASM (Assembly) | **MC-ASM-002** | Assemblyenginecaseuse | **FLAG** - near-duplicate of `assemblyenginecase`. Confirm which is current. No drawing yet. |
| `lswugpart2.SLDPRT` | `frame\99_Unsorted - Review` | UNK (Part) | **MC-UNK-002** | Unidentified Part 2 | **AMBIGUOUS** - generic name, no type inferable. Needs your input. No drawing yet. |
| `part.SLDPRT` | `frame\99_Unsorted - Review` | UNK (Part) | **MC-UNK-001** | Unidentified Part | **AMBIGUOUS** - generic name, no type inferable. Needs your input. No drawing yet. |
| `airintake_mandifold.SLDPRT` | `frame\Assembly` | MAN (Part) | **MC-MAN-001** | Air Intake Manifold | **FLAG** - filename misspells 'manifold'. Do NOT rename; title corrected here only. No drawing yet. |
| `Assem3.SLDASM` | `frame\Assembly` | ASM (Assembly) | **MC-ASM-010** | Assem3 | **AMBIGUOUS** - default SolidWorks name, contents unknown. Needs your input. No drawing yet. |
| `camchainassembly_ed.SLDASM` | `frame\Assembly` | ASM (Assembly) | **MC-ASM-007** | Camchainassembly Ed | **FLAG** - one of three cam chain assemblies. Confirm which is current. No drawing yet. |
| `camchainassembly_ed2.SLDASM` | `frame\Assembly` | ASM (Assembly) | **MC-ASM-008** | Camchainassembly Ed2 | **FLAG** - one of three cam chain assemblies. Confirm which is current. No drawing yet. |
| `camchains_assembly.SLDASM` | `frame\Assembly` | ASM (Assembly) | **MC-ASM-006** | Camchains Assembly | **FLAG** - one of three cam chain assemblies. Confirm which is current. No drawing yet. |
| `clutchhub-assembly.SLDASM` | `frame\Assembly` | ASM (Assembly) | **MC-ASM-003** | Clutchhub Assembly | **FLAG** - near-duplicate of `clutchhubassembly`. Confirm which is current. No drawing yet. |
| `clutchhubassembly.SLDASM` | `frame\Assembly` | ASM (Assembly) | **MC-ASM-009** | Clutchhubassembly | **FLAG** - near-duplicate of `clutchhub-assembly`. Confirm which is current. No drawing yet. |
| `crankshaft_assembly.SLDASM` | `frame\Assembly` | ASM (Assembly) | **MC-ASM-005** | Crankshaft Assembly | No drawing yet. |
| `engine_assembly.SLDASM` | `frame\Assembly` | ASM (Assembly) | **MC-ASM-014** | Engine Assembly | No drawing yet. |
| `enginegearsassembly.SLDASM` | `frame\Assembly` | ASM (Assembly) | **MC-ASM-011** | Enginegearsassembly | No drawing yet. |
| `enginehead_assembly.SLDASM` | `frame\Assembly` | ASM (Assembly) | **MC-ASM-013** | Enginehead Assembly | No drawing yet. |
| `headlight_assembly.SLDASM` | `frame\Assembly` | ASM (Assembly) | **MC-ASM-021** | Headlight Assembly | No drawing yet. |
| `piston assembly.SLDASM` | `frame\Assembly` | ASM (Assembly) | **MC-ASM-004** | Piston Assembly | No drawing yet. |
| `rear foot rest front and mirror assembly.SLDASM` | `frame\Assembly` | ASM (Assembly) | **MC-ASM-019** | Rear Foot Rest Front And Mirror Assembly | No drawing yet. |
| `rear foot rest front assembly.SLDASM` | `frame\Assembly` | ASM (Assembly) | **MC-ASM-020** | Rear Foot Rest Front Assembly | No drawing yet. |
| `rearwheel_assembly.SLDASM` | `frame\Assembly` | ASM (Assembly) | **MC-ASM-016** | Rearwheel Assembly | No drawing yet. |
| `rearwheel_frame_aseembly.SLDASM` | `frame\Assembly` | ASM (Assembly) | **MC-ASM-018** | Rearwheel Frame Aseembly | No drawing yet. |
| `shockabsorber_assembly.SLDASM` | `frame\Assembly` | ASM (Assembly) | **MC-ASM-015** | Shockabsorber Assembly | No drawing yet. |
| `chain_guard.SLDPRT` | `frame\Chain` | GRD (Part) | **MC-GRD-004** | Chain Guard | No drawing yet. |
| `chain_inner.SLDPRT` | `frame\Chain` | CHN (Part) | **MC-CHN-003** | Chain Inner | No drawing yet. |
| `chain_outer.SLDPRT` | `frame\Chain` | CHN (Part) | **MC-CHN-004** | Chain Outer | No drawing yet. |

## Items needing your decision

- `airintake_mandifold.SLDPRT` (frame\Assembly) - **FLAG** - filename misspells 'manifold'. Do NOT rename; title corrected here only.
- `Assem3.SLDASM` (frame\Assembly) - **AMBIGUOUS** - default SolidWorks name, contents unknown. Needs your input.
- `assemblyenginecase.SLDASM` (frame\43_Engine Assembly) - **FLAG** - near-duplicate of `assemblyenginecaseuse`. Confirm which is current.
- `assemblyenginecaseuse.SLDASM` (frame\43_Engine Assembly) - **FLAG** - near-duplicate of `assemblyenginecase`. Confirm which is current.
- `camchainassembly_ed.SLDASM` (frame\Assembly) - **FLAG** - one of three cam chain assemblies. Confirm which is current.
- `camchainassembly_ed2.SLDASM` (frame\Assembly) - **FLAG** - one of three cam chain assemblies. Confirm which is current.
- `camchains_assembly.SLDASM` (frame\Assembly) - **FLAG** - one of three cam chain assemblies. Confirm which is current.
- `clutch_hub_gear_bearing.SLDPRT` (frame\04_Clutch Hub Parts) - Typed by noun head (`bearing`), not the `gear` in the name.
- `clutch_hub_gear_pin.SLDPRT` (frame\04_Clutch Hub Parts) - Typed by noun head (`pin`), not the `gear` in the name.
- `clutch_hub_gear_plate.SLDPRT` (frame\04_Clutch Hub Parts) - Typed by noun head (`plate`), not the `gear` in the name.
- `clutchhub-assembly.SLDASM` (frame\Assembly) - **FLAG** - near-duplicate of `clutchhubassembly`. Confirm which is current.
- `clutchhubassembly.SLDASM` (frame\Assembly) - **FLAG** - near-duplicate of `clutchhub-assembly`. Confirm which is current.
- `front_wheel_frame_shaft_boltdd.SLDPRT` (frame\24_Front Wheel Parts) - **FLAG** - `dd` suffix suggests a stray duplicate of `front_wheel_frame_shaft_bolt`.
- `lswugpart2.SLDPRT` (frame\99_Unsorted - Review) - **AMBIGUOUS** - generic name, no type inferable. Needs your input.
- `part.SLDPRT` (frame\99_Unsorted - Review) - **AMBIGUOUS** - generic name, no type inferable. Needs your input.
- `piston_bushing_Eng_Drw.SLDPRT` (frame\16_Piston Parts) - **FLAG** - `Eng_Drw` suffix is unusual; confirm it is the production part.
- `rear_wheel_frame_18mm.SLDPRT` (frame\23_Rear Wheel Parts) - **FLAG** - size variant of `rear_wheel_frame`; may be an alternate config rather than a distinct drawing.
- `rear_wheel_frame_as_bolt.SLDPRT` (frame\23_Rear Wheel Parts) - **FLAG** - `as` is unclear (absorber shaft?). Title is a guess.
- `rear_wheel_frame_connector_shaf.SLDPRT` (frame\23_Rear Wheel Parts) - **FLAG** - filename appears truncated (`shaf` -> `shaft`). Do NOT rename; noted only.
- `rear_wheel_frame_old.SLDPRT` (frame\23_Rear Wheel Parts) - **FLAG** - `_old` suggests superseded by `rear_wheel_frame`. Confirm before numbering.
- `testscrew.SLDPRT` (frame\20_Bolts - Various) - **FLAG** - looks like a throwaway test file. Confirm it belongs in the release set.

## Sequencing

Sequence order uses **filesystem creation date**, which for this project is when each file landed in `Downloads` - not necessarily when you designed the part. Dates run 2026-04-22 to 2026-09-03 and track the folder order closely, so the result is sensible, but if you want strict alphabetical or strict folder order instead, say so and I will renumber.

## Open issues

1. **Only 3 of 192 documents are drawings.** The macro in Step 4 can only write properties to a `.SLDDRW` that exists. See the note in chat about writing the properties to the models instead so drawings inherit them.

2. **Lock files present** - these were excluded from the index, but they mean the documents are open in SolidWorks now or were left behind by a crash. Close them before running any macro:

   - `frame\04_Clutch Hub Parts\~$clutch_hub_basket_mced.SLDDRW`
   - `frame\04_Clutch Hub Parts\~$clutch_hub_basket_mced.SLDPRT`

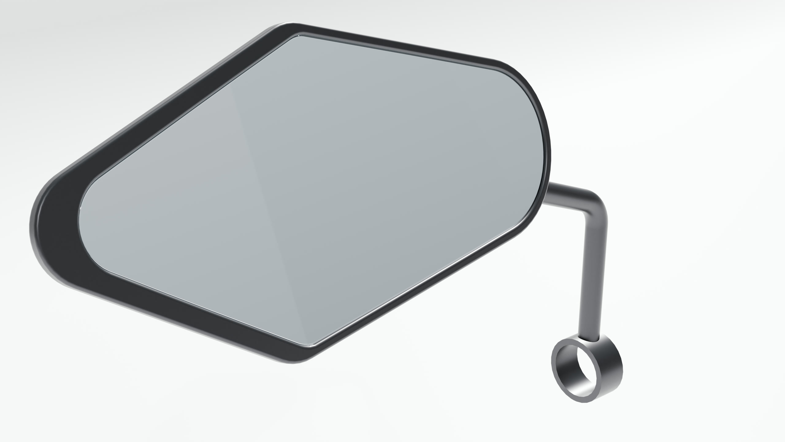
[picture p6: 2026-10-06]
media/renders/wingmirror.jpg

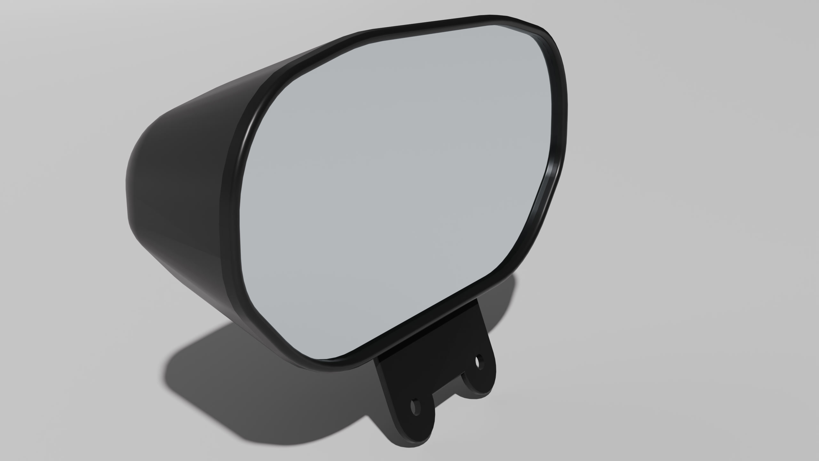
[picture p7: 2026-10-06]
media/renders/speedometerside.jpg

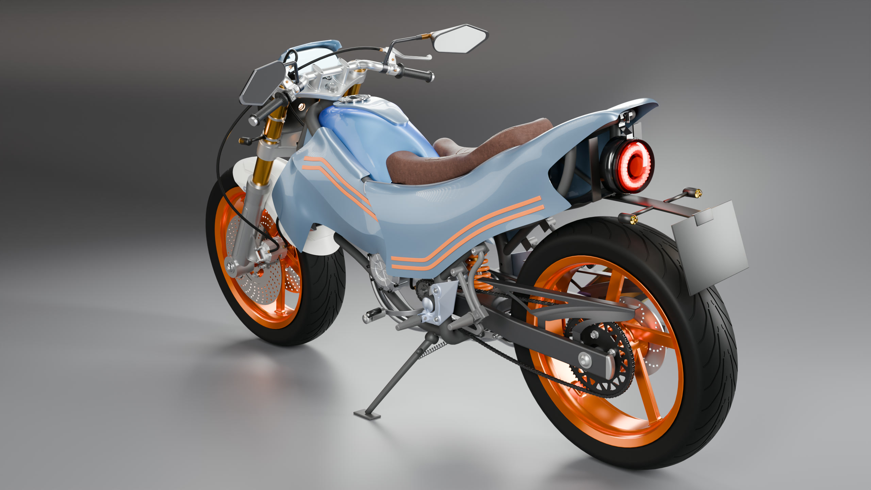
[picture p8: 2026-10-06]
media/renders/motocyclefinalv4isometricview2.jpg

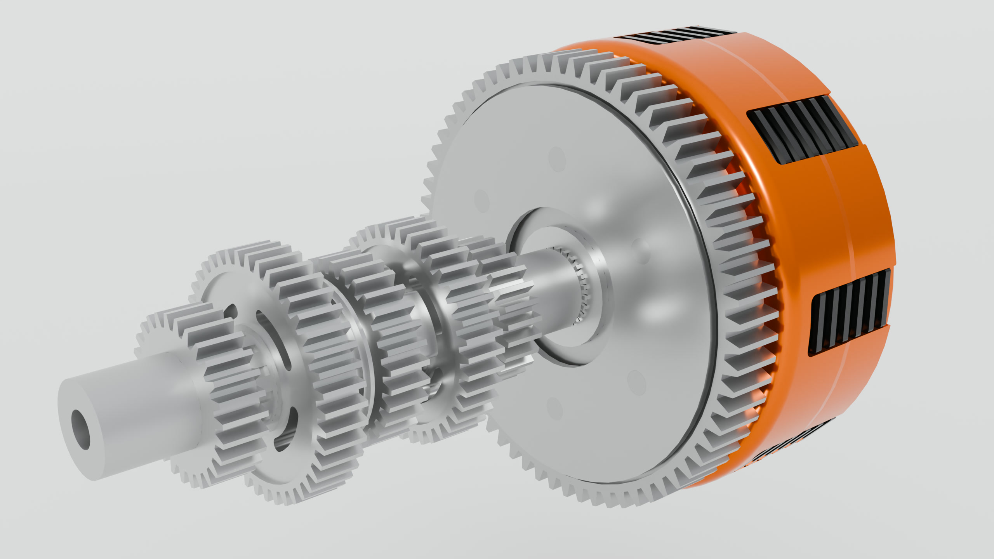
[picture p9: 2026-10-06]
media/renders/clutchhub.jpg

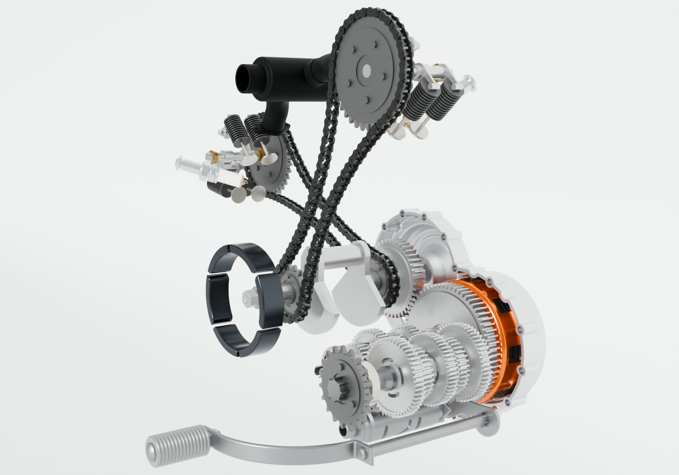
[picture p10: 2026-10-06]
media/renders/engineexploded.jpg

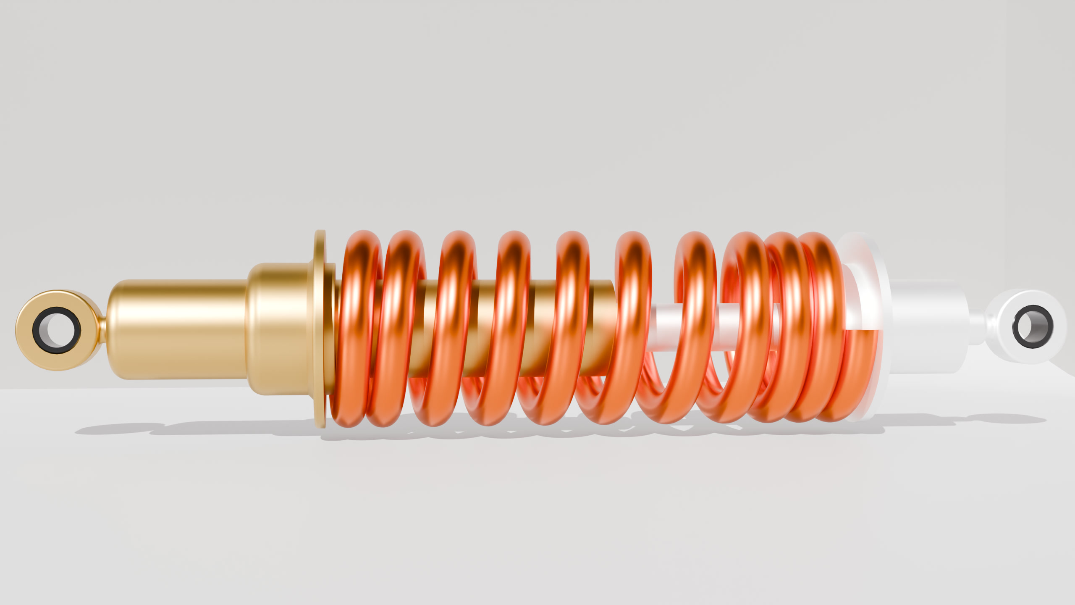
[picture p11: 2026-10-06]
media/renders/shockabsorbrfront101.jpg

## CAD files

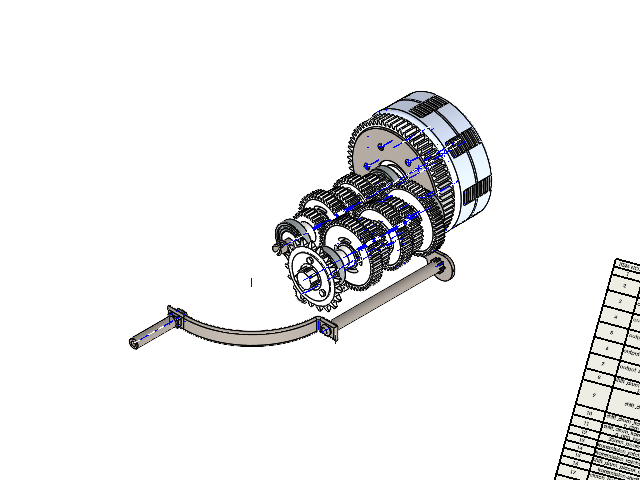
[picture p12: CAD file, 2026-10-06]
cad/Assembly/enginegearsassembly.SLDASM
clutch_hub_basket_mced
basket_gear_mced
clutch_hub_inner_hub
clutch_hub_friction_plate x 6
clutch-hub-steel-plate x 6
clutch_hub_pressure_plate
clutch_hub_pressure_spring x 4
clutch_hub_pressure_bolt x 4
clutch_hub_gear_plate
clutch_hub_gear_bearing x 6
clutch_hub_gear_pin x 6
clutch-hub-shaft-nut
input_shaft
input_shaft_gear_one
input_shaft_gear_two
input_shaft_gear_three
input_shaft_gear_four
input_shaft_gear_five
output_shaft
output_shaft_gear_one
output_shaft_gear_two
output_shaft_gear_five
output_shaft_gear_four
output_shaft_gear_three
shift_drum_gear_arms_pin
shift_drum
shift_drum_transmission_arm x 2
shift_drum_transmission_arm_two
20mm_bearing_balls_mced x 4
20mm_bearing_inner_ring_mced x 4
20mm_bearing_outer_ring_mced x 4
transmission_ratchet_a
transmission_ratchet_b
shift_drum_placer_arm
transmission-shaft
clutch_hub_pressure_shaft
hand_brake_cable_connector
output_shaft_sprocket

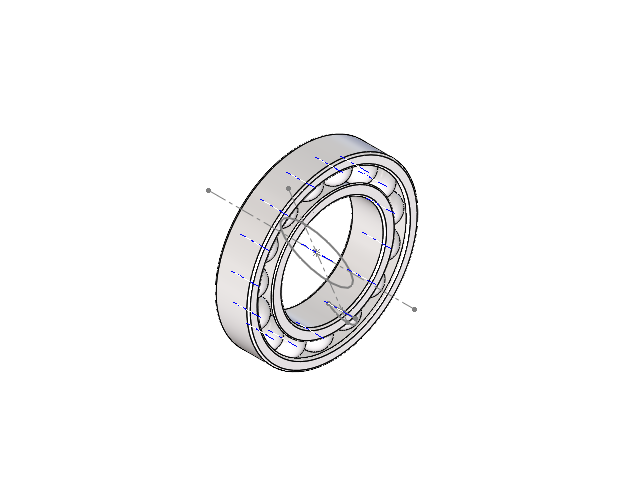
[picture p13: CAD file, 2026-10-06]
cad/19_20mm and 30mm Ball Bearings/30mm_bearing.SLDASM
30mm_bearing_balls_mced
30mm_bearing_inner_ring_mced
30mm_bearing_outer_ring_mced

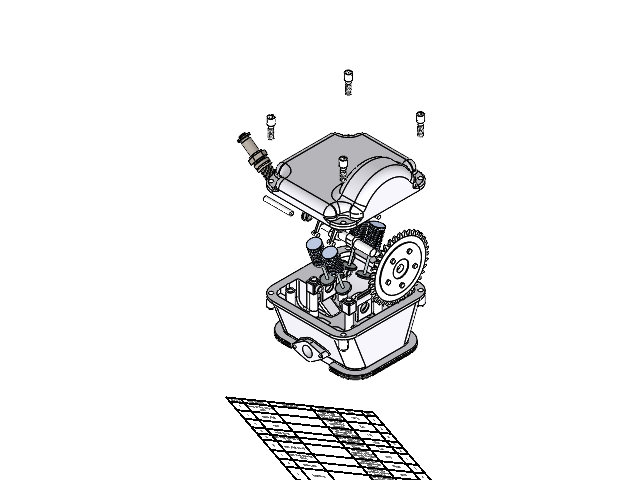
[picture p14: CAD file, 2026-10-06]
cad/Assembly/enginehead_assembly.SLDASM
valve_section_engine_case
rocker_shaft x 2
valve x 4
valve-spring x 4
cam_shaft_bushing_mced x 2
cam_shaft_mced
cam_shaft_sprocket_mced
rocker_arm x 2
Spark Plug
engine_head_case
bolt_head_case_mced x 4

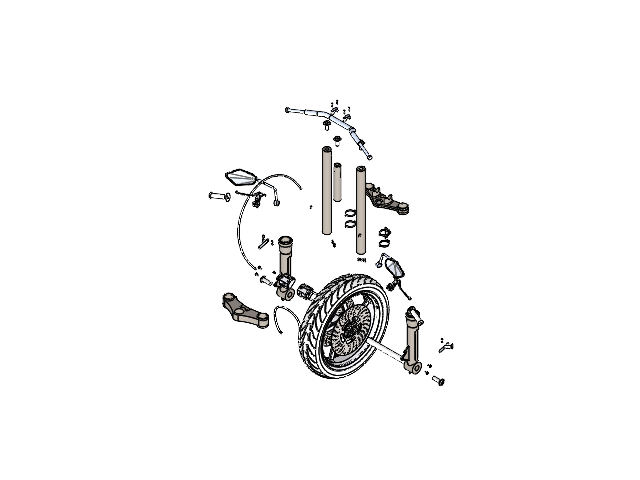
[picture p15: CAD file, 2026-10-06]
cad/Assembly/frontwheelframe_assembly.SLDASM
front_wheel_m_frame_inner_pipe
front_wheel_upper_connector_arm
front_wheel_side_pipe x 2
wheel_rim
tyre
30mm_bearing_balls_mced x 2
30mm_bearing_inner_ring_mced x 2
30mm_bearing_outer_ring_mced x 2
front_wheel_brake_plate
front_wheel_brake_plate_left
rear_wheel_sprocket_bolt x 10
front_wheel_lower_connector_arm
front_wheel_shaft
front_wheel_frame_shaft_bolt x 2
front_wheel_side_pipe_top_bolt x 3
handle_bar_connector_arm_bridge x 2
handle_bar
bolt_front_wheel_frame_clamp_mced x 4
handle_bar_connector_bridge_pin x 4
handle_bar_grip x 2
wing-mirror-arm
wing-mirror-connector
wing-mirror-case
wing-mirror-mirror
wing-mirror-arm_mirror
wing-mirror-connector_mirror
wing-mirror-case_mirror
wing-mirror-mirror_mirror
front_wheel_guard_bridge
front_wheel_guard_bridge_pin_a x 4
front_wheel_guard_bridge_mirror
headlight_connector_arm
headlight_connector_arm_mirror
front_wheel_brake_body
front_wheel_side_base_pipe x 2
front_wheel_brake_body_mirror2
hand_brake_cable_connector x 9
hand_brake_lever x 2
hand_brake_body x 2
hand_brake_handlebar_bridge x 2
hand_brake_pin x 2
connectingcable
connectingcable2
shock_absorber_pin_a_bolt x 4
light-frame-pin x 2

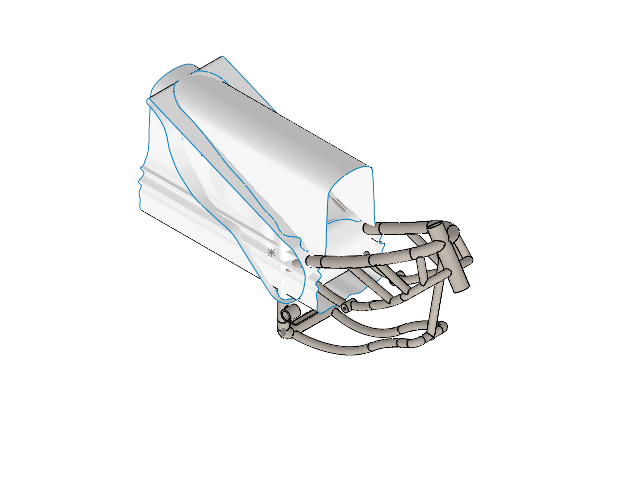
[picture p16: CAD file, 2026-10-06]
cad/body/frameandbody.SLDASM
frame
rearbody2

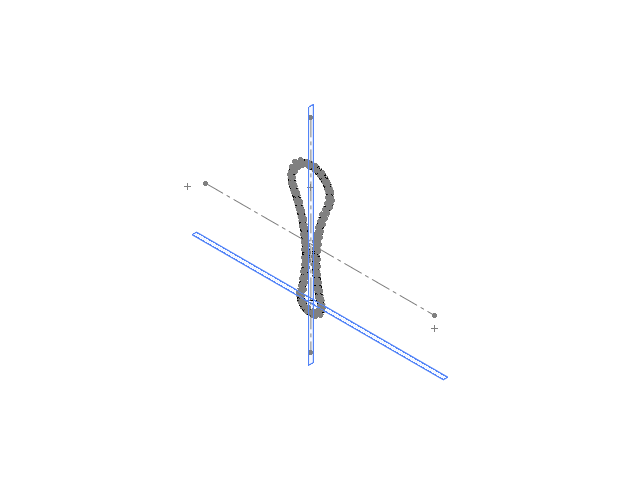
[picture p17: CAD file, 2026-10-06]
cad/Assembly/camchainassembly_ed2.SLDASM
cam_chain_inner_mced x 44
cam_chain_outer_mced x 44

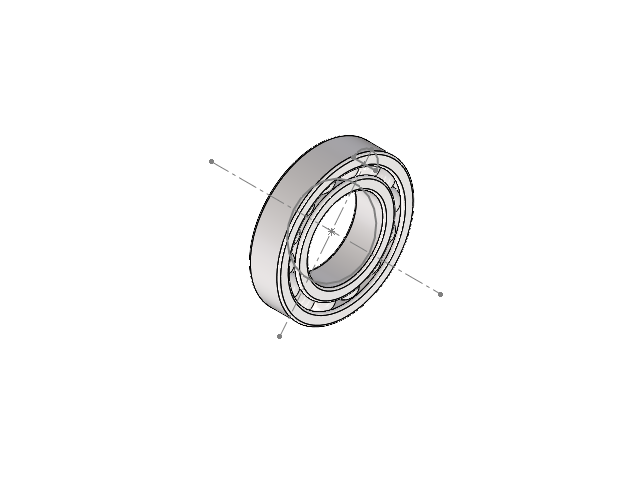
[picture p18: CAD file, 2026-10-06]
cad/19_20mm and 30mm Ball Bearings/20mm_bearing.SLDASM
20mm_bearing_balls_mced
20mm_bearing_inner_ring_mced
20mm_bearing_outer_ring_mced

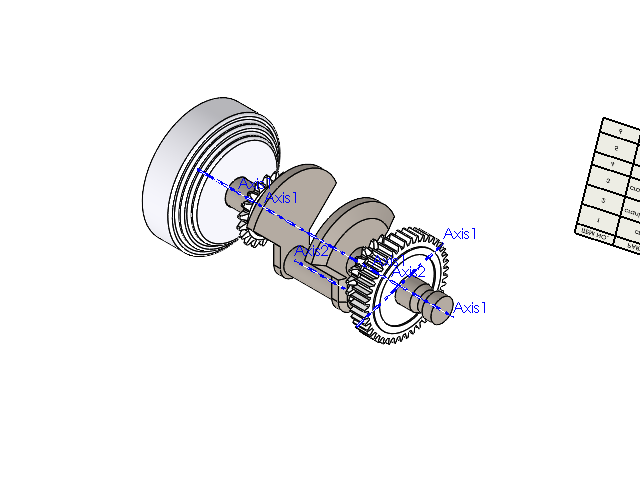
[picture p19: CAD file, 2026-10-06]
cad/Assembly/crankshaft_assembly.SLDASM
crank_shaft
crank_shaft_gear_one
crank_shaft_sprocket x 2
stator_case
stator_magnets
stator_nut

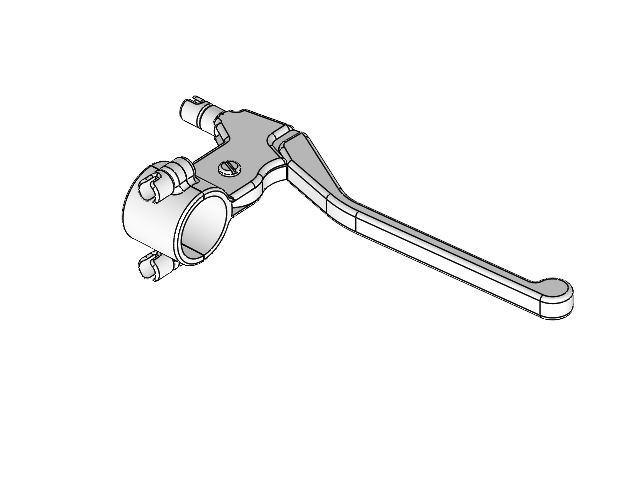
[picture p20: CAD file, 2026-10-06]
cad/Assembly/handbrake_assembly.SLDASM
hand_brake_lever
hand_brake_body
hand_brake_handlebar_bridge
hand_brake_pin
hand_brake_cable_connector x 3

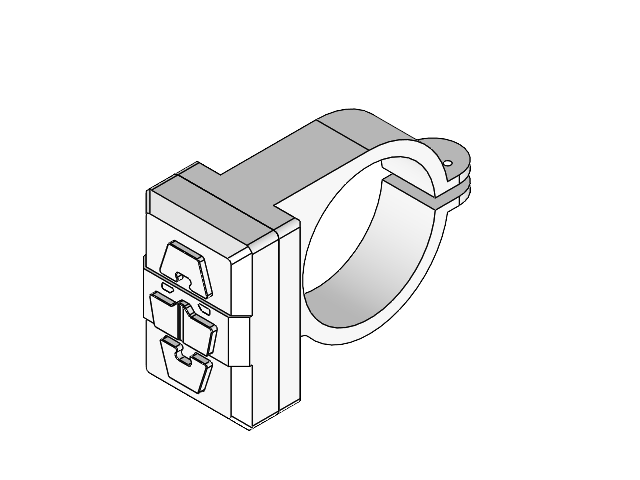
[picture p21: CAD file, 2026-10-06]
cad/Assembly/handlecontrolbox.SLDASM
case
button1
button2
button3
leds x 2
caseback

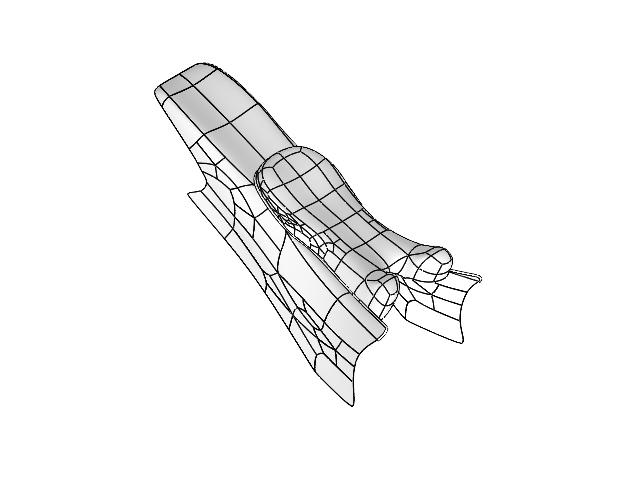
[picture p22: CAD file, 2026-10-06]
cad/Assembly/assembly-rearbody-seatertrim-seater.SLDASM
seatrim
rearbody.stp
seater221v4.stp

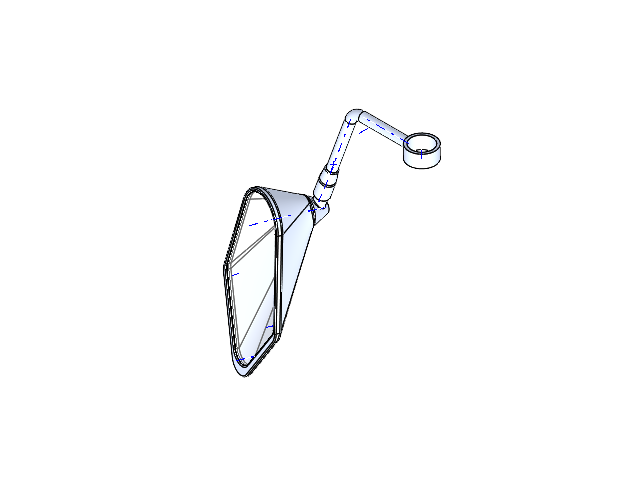
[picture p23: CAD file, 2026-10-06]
cad/Assembly/wingmirror_assembly.SLDASM
wing-mirror-arm
wing-mirror-connector
wing-mirror-case
wing-mirror-mirror

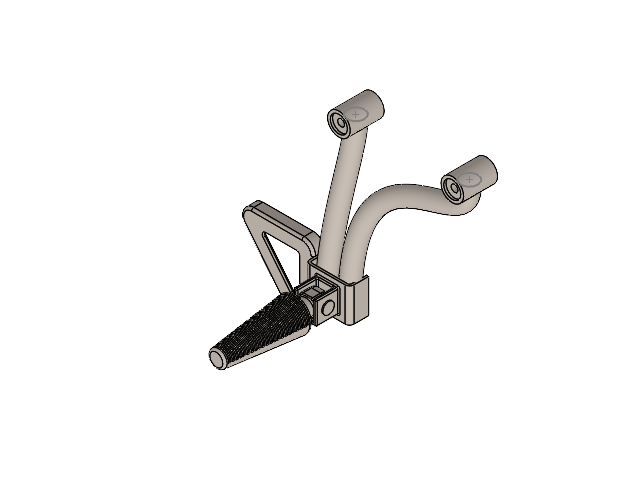
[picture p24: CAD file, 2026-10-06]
cad/Assembly/rear foot rest front assembly.SLDASM
rear_foot_rest_frame
foot_rest
foot_rest_pin

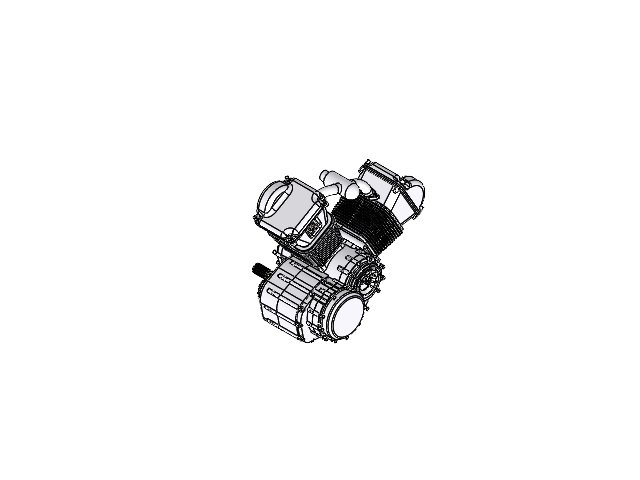
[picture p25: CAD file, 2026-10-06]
cad/Assembly/engine_assembly.SLDASM
left-side-engine-case
right-side-engine-case
crank_shaft
crank_shaft_gear_one
crank_shaft_sprocket x 2
stator_case
stator_magnets
stator_nut
clutch_hub_basket_mced
basket_gear_mced
clutch_hub_inner_hub
clutch_hub_friction_plate x 6
clutch-hub-steel-plate x 6
clutch_hub_pressure_plate
clutch_hub_pressure_spring x 4
clutch_hub_pressure_bolt x 4
clutch_hub_gear_plate
clutch_hub_gear_bearing x 6
clutch_hub_gear_pin x 6
clutch-hub-shaft-nut
input_shaft
input_shaft_gear_one
input_shaft_gear_two
input_shaft_gear_three
input_shaft_gear_four
input_shaft_gear_five
output_shaft
output_shaft_gear_one
output_shaft_gear_two
output_shaft_gear_five
output_shaft_gear_four
output_shaft_gear_three
shift_drum_gear_arms_pin
shift_drum
shift_drum_transmission_arm x 2
shift_drum_transmission_arm_two
20mm_bearing_balls_mced x 4
20mm_bearing_inner_ring_mced x 4
20mm_bearing_outer_ring_mced x 4
transmission_ratchet_a
transmission_ratchet_b
shift_drum_placer_arm
transmission-shaft
clutch_hub_pressure_shaft
hand_brake_cable_connector
output_shaft_sprocket
stator_engine_case
clutch_hub_engine_case_mced
cylinder_section_engine_case x 2
valve_section_engine_case x 2
rocker_shaft x 4
valve x 8
valve-spring x 8
cam_shaft_bushing_mced x 4
cam_shaft_mced x 2
cam_shaft_sprocket_mced x 2
rocker_arm x 4
Spark Plug x 2
engine_head_case x 2
bolt_head_case_mced x 8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

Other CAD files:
cad/43_Engine Assembly/assemblyenginecase.SLDASM
cad/43_Engine Assembly/assemblyenginecaseuse.SLDASM
cad/01_Introduction - Motorcycle Frame/framesketchass.SLDASM
cad/Assembly/camchainassembly_ed.SLDASM
cad/01_Introduction - Motorcycle Frame/bottomconnector.SLDPRT
cad/01_Introduction - Motorcycle Frame/frame.SLDPRT
cad/01_Introduction - Motorcycle Frame/frame123.STEP
cad/01_Introduction - Motorcycle Frame/frame_chassis.SLDPRT
cad/01_Introduction - Motorcycle Frame/framesketch.SLDPRT
cad/01_Introduction - Motorcycle Frame/framesketch_passedfos.SLDPRT
cad/01_Introduction - Motorcycle Frame/rearbodysection.sldprt
cad/02_Left Side Engine Case/left-side-engine-case.SLDPRT
cad/03_Right Side Engine Case/right-side-engine-case.SLDDRW
cad/03_Right Side Engine Case/right-side-engine-case.SLDPRT
cad/03_Right Side Engine Case/right-side-engine-case2.SLDDRW
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

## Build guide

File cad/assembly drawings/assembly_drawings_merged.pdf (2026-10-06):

E | E
F | F

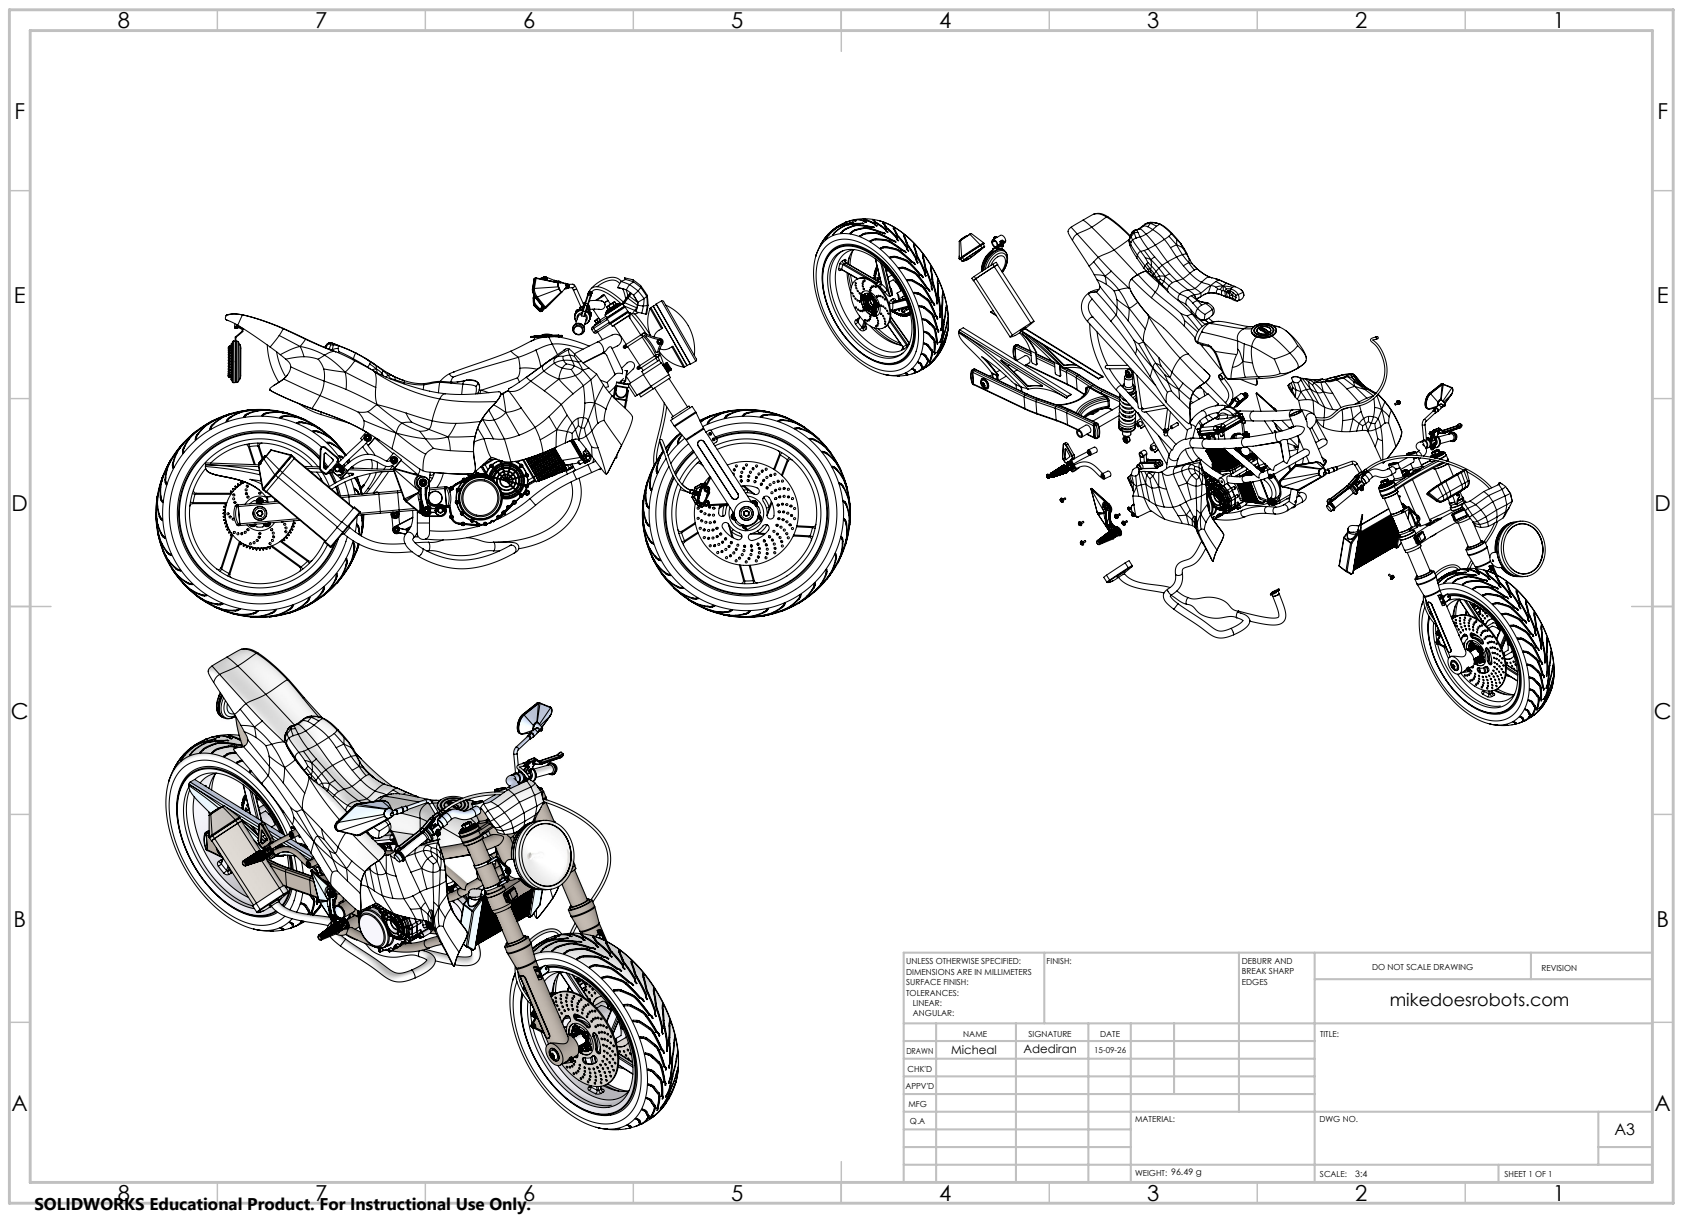
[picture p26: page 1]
FINISH:; DEBURR AND; BREAK SHARP EDGES; DO NOT SCALE DRAWING; REVISION; SCALE:; SHEET 1 OF 1; WEIGHT:; mikedoesrobots.com

UNLESS OTHERWISE SPECIFIED:
DIMENSIONS ARE IN MILLIMETERS
SURFACE FINISH:
TOLERANCES:
LINEAR:
ANGULAR:

NAME | SIGNATURE | DATE | | | | TITLE:

DRAWN | Micheal | Adediran | 15-09-26

CHK'D
APPV'D
MFG
Q.A | | | | MATERIAL: | DWG NO. | A3

SOLIDWORKS Educational Product. For Instructional Use Only.

ITEM NO. | PART NUMBER | DESCRIPTION | QTY.
1 | foot_rest_kick_guard | | 1

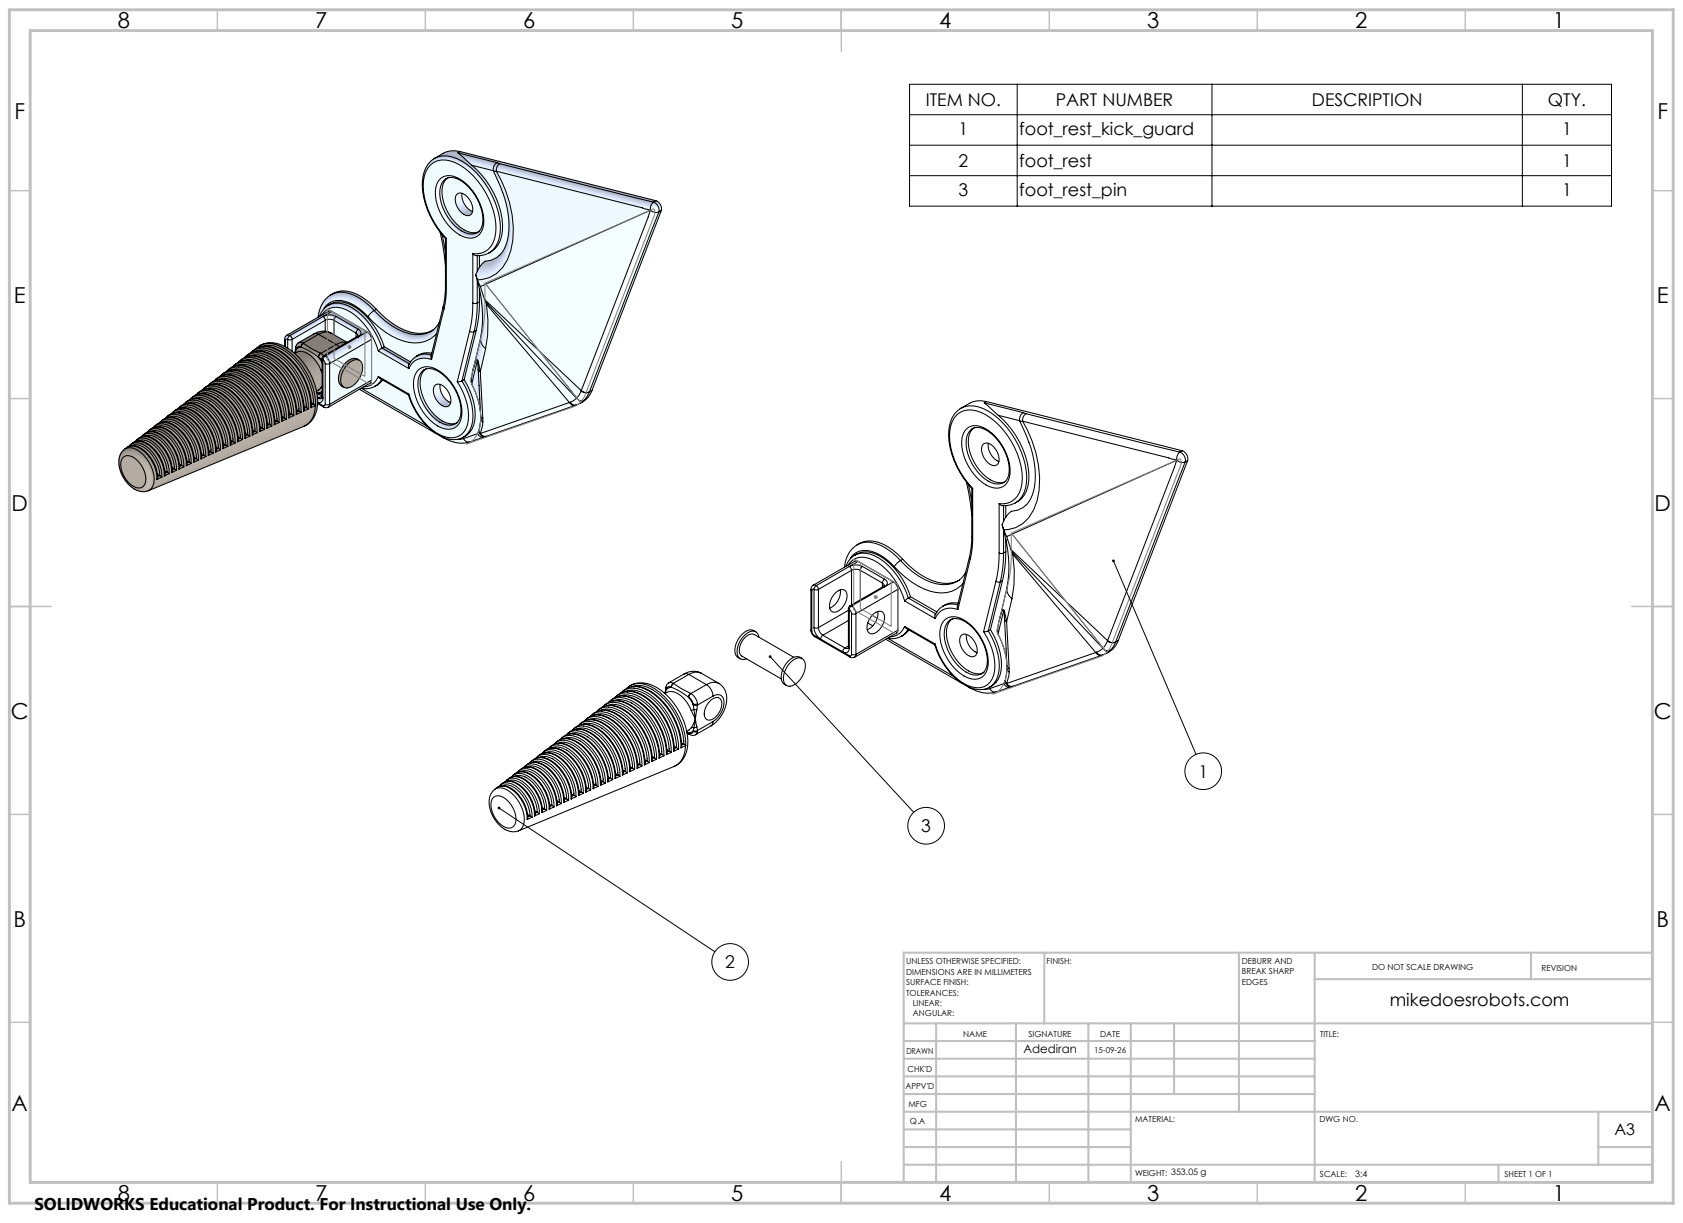
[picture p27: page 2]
FINISH:; DEBURR AND; BREAK SHARP EDGES; DO NOT SCALE DRAWING; REVISION; mikedoesrobots.com

2 | foot_rest | | 1
3 | foot_rest_pin | | 1

UNLESS OTHERWISE SPECIFIED:
DIMENSIONS ARE IN MILLIMETERS
SURFACE FINISH:
TOLERANCES:
LINEAR:
ANGULAR:

NAME | SIGNATURE | DATE | TITLE:

DRAWN | | Adediran | 15-09-26

CHK'D
APPV'D
MFG

ITEM NO. | PART NUMBER | DESCRIPTION | QTY.
1 | wheel_rim | | 1

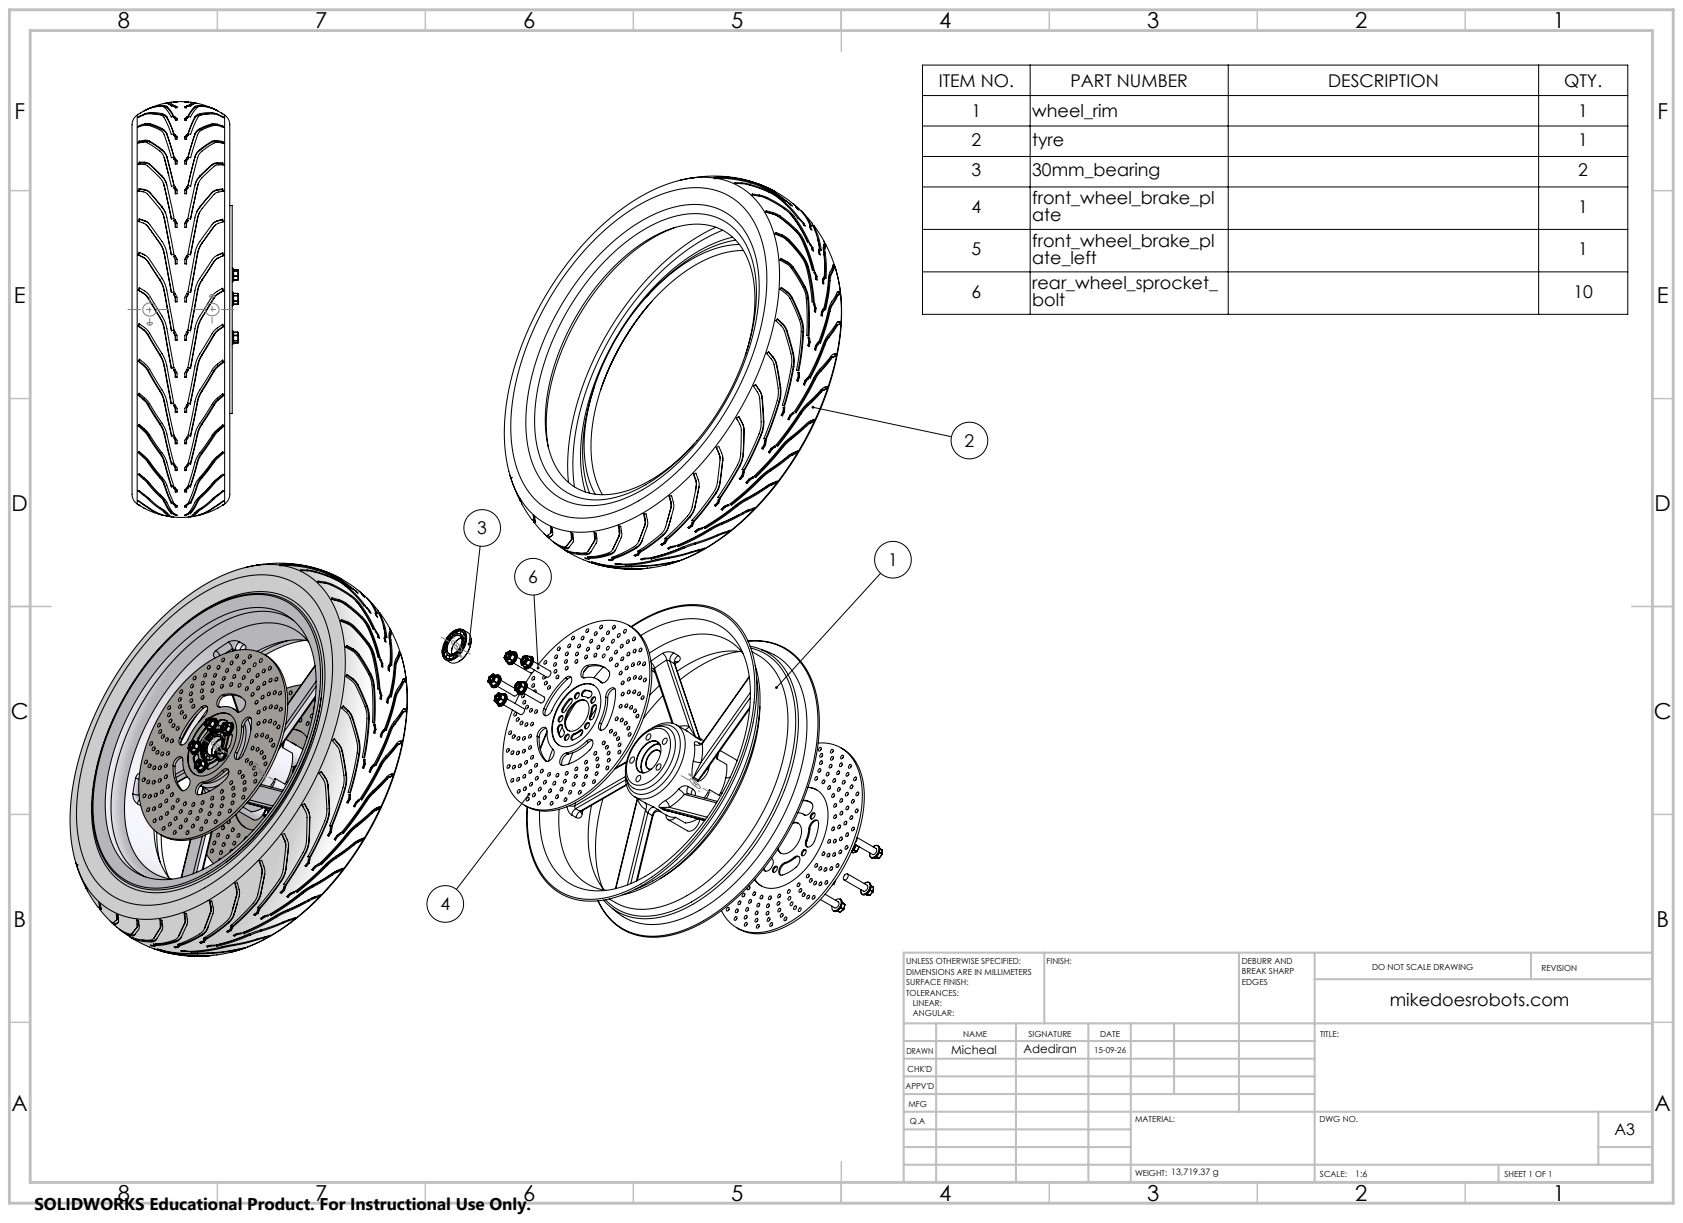
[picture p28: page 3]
front_wheel_brake_pl; ate; FINISH:; DEBURR AND; BREAK SHARP EDGES; DO NOT SCALE DRAWING; REVISION; mikedoesrobots.com

2 | tyre | | 1
3 | 30mm_bearing | | 2

5 | front_wheel_brake_pl ate_left | 1
6 | rear_wheel_sprocket_ bolt | 10

UNLESS OTHERWISE SPECIFIED:
DIMENSIONS ARE IN MILLIMETERS
SURFACE FINISH:
TOLERANCES:
LINEAR:
ANGULAR:

NAME | SIGNATURE | DATE | TITLE:

DRAWN | Micheal | Adediran | 15-09-26

CHK'D
APPV'D
MFG

ITEM NO. | PART NUMBER | DESCRIPTION | QTY.
1 | hand_brake_lever | | 1

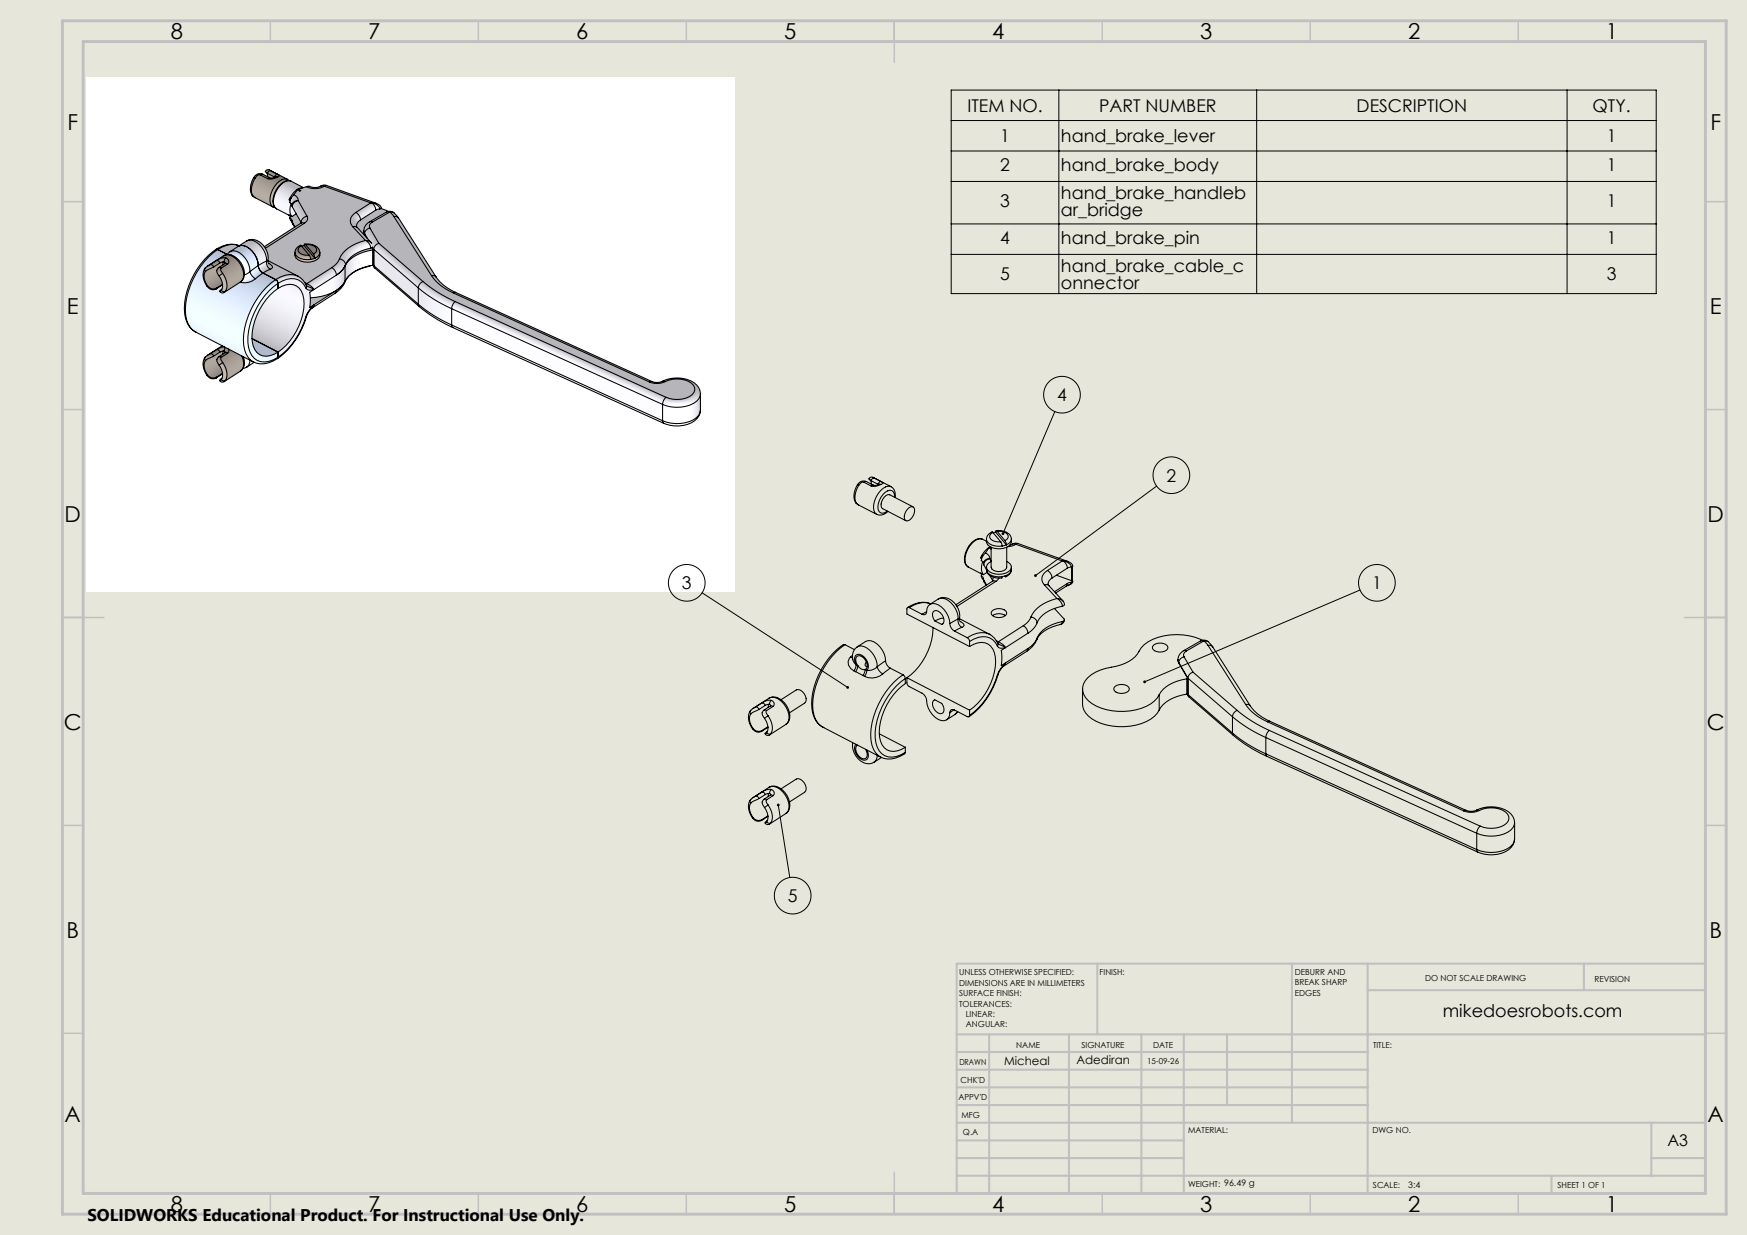
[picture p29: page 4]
FINISH:; DEBURR AND; BREAK SHARP EDGES; DO NOT SCALE DRAWING; REVISION; mikedoesrobots.com

2 | hand_brake_body | | 1
3 | hand_brake_handleb ar_bridge | | 1
4 | hand_brake_pin | | 1
5 | hand_brake_cable_c onnector | | 3

UNLESS OTHERWISE SPECIFIED:
DIMENSIONS ARE IN MILLIMETERS
SURFACE FINISH:
TOLERANCES:
LINEAR:
ANGULAR:

NAME | SIGNATURE | DATE | TITLE:

DRAWN | Micheal | Adediran | 15-09-26

CHK'D
APPV'D
MFG

ITEM NO. | PART NAME | MATERIAL | QTY.
1 | wheel_rim | | 1

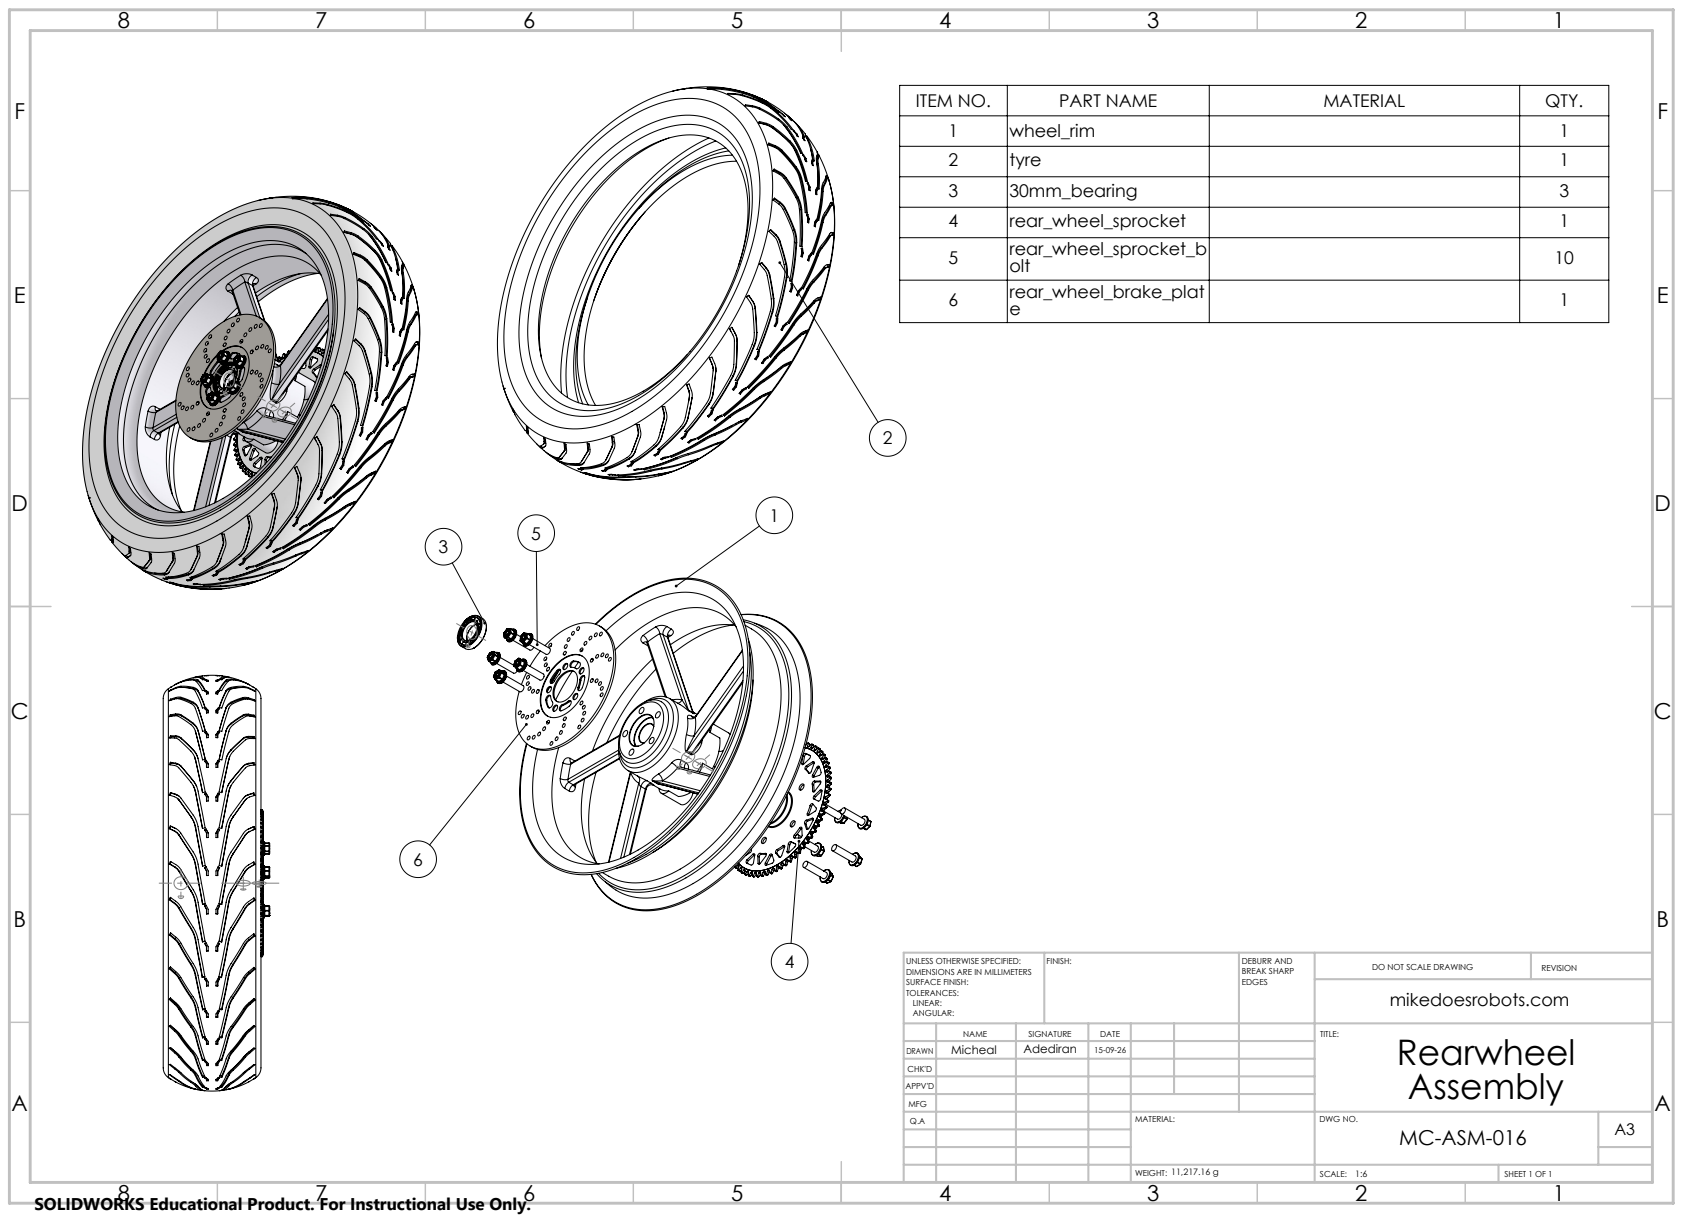
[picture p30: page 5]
FINISH:; DEBURR AND; BREAK SHARP EDGES; DO NOT SCALE DRAWING; REVISION; mikedoesrobots.com

2 | tyre | | 1
3 | 30mm_bearing | | 3
4 | rear_wheel_sprocket | | 1
5 | rear_wheel_sprocket_b olt | | 10
6 | rear_wheel_brake_plat e | | 1

UNLESS OTHERWISE SPECIFIED:
DIMENSIONS ARE IN MILLIMETERS
SURFACE FINISH:
TOLERANCES:
LINEAR:
ANGULAR:

DRAWN | Micheal | Adediran | 15-09-26

NAME | SIGNATURE | DATE | | | TITLE: Rearwheel Assembly

CHK'D
APPV'D
MFG

MC-ASM-016

6

9

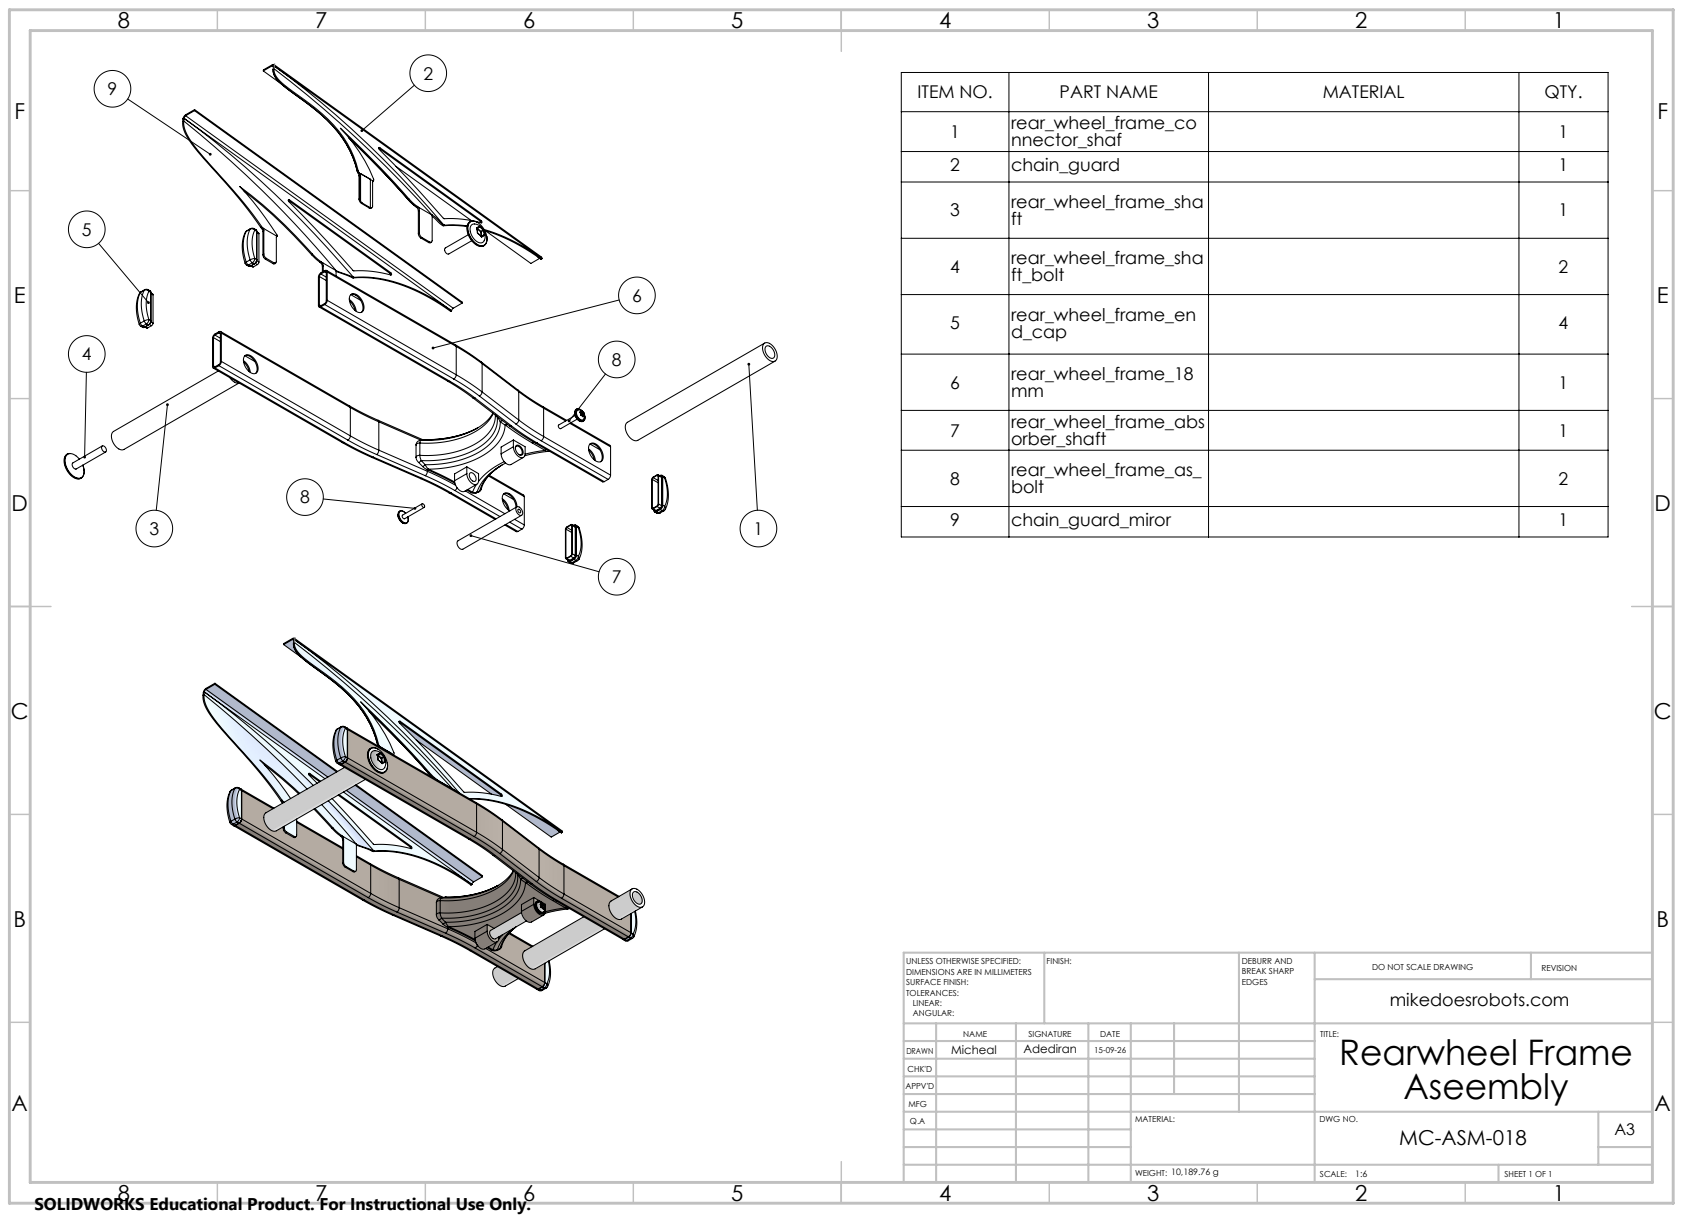
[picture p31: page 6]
FINISH:; DEBURR AND; BREAK SHARP EDGES; DO NOT SCALE DRAWING; REVISION; mikedoesrobots.com

ITEM NO. | PART NAME | MATERIAL | QTY.
1 | rear_wheel_frame_co nnector_shaf | | 1
2 | chain_guard | | 1
3 | rear_wheel_frame_sha ft | | 1

4 | rear_wheel_frame_sha ft_bolt | | 2

5 | rear_wheel_frame_en d_cap | | 4

6 | rear_wheel_frame_18 mm | | 1

7 | rear_wheel_frame_abs orber_shaft | | 1

8 | rear_wheel_frame_as_ bolt | | 2

9 | chain_guard_miror | | 1

UNLESS OTHERWISE SPECIFIED:
DIMENSIONS ARE IN MILLIMETERS
SURFACE FINISH:
TOLERANCES:
LINEAR:
ANGULAR:

DRAWN | Micheal | Adediran | 15-09-26

NAME | SIGNATURE | DATE | TITLE: Rearwheel Frame Aseembly

CHK'D
APPV'D
MFG

1

ITEM NO. | PART NAME | MATERIAL | QTY.

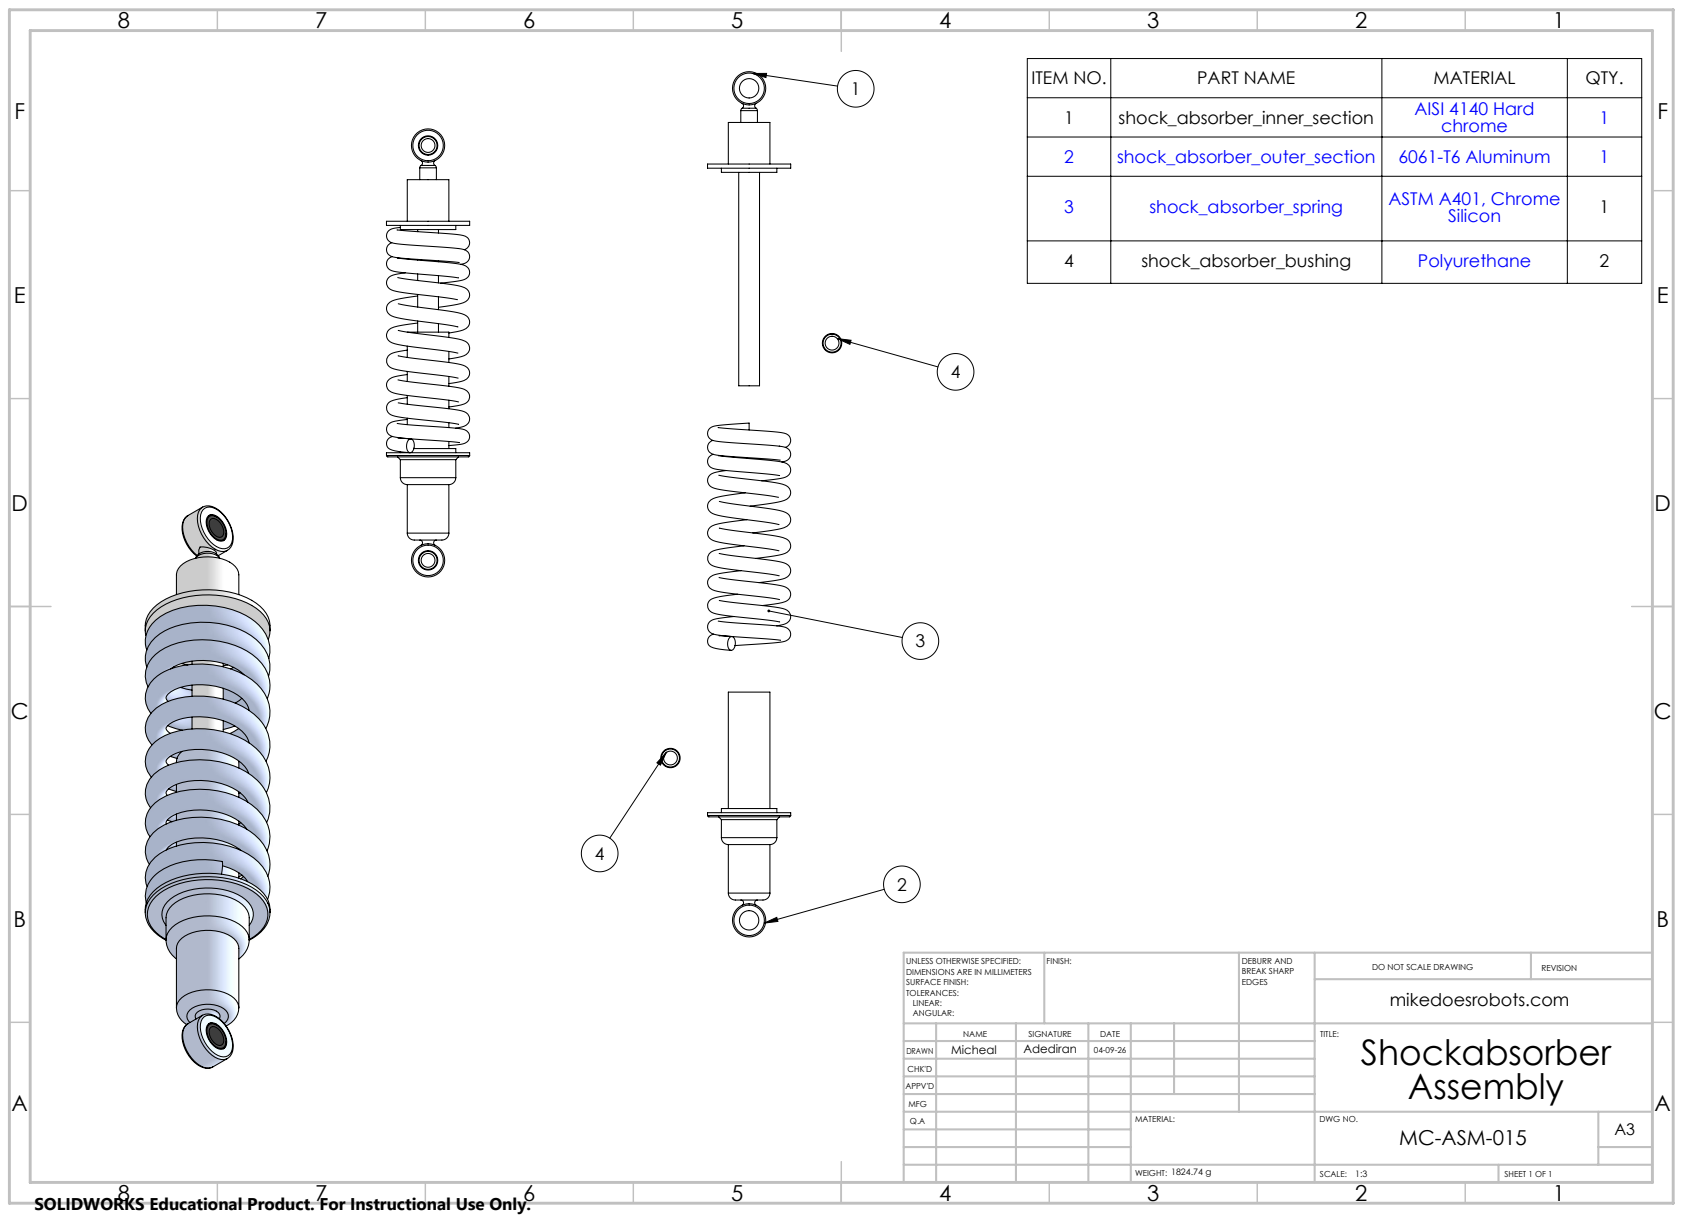
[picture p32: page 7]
FINISH:; DEBURR AND; BREAK SHARP EDGES; DO NOT SCALE DRAWING; REVISION; mikedoesrobots.com

1 | shock_absorber_inner_section | AISI 4140 Hard chrome | 1

2 | shock_absorber_outer_section | 6061-T6 Aluminum | 1
3 | shock_absorber_spring | ASTM A401, Chrome Silicon | 1

4 | shock_absorber_bushing | Polyurethane | 2

UNLESS OTHERWISE SPECIFIED:
DIMENSIONS ARE IN MILLIMETERS
SURFACE FINISH:
TOLERANCES:
LINEAR:
ANGULAR:

DRAWN | Micheal | Adediran | 04-09-26

NAME | SIGNATURE | DATE | TITLE: Shockabsorber Assembly

CHK'D
APPV'D
MFG

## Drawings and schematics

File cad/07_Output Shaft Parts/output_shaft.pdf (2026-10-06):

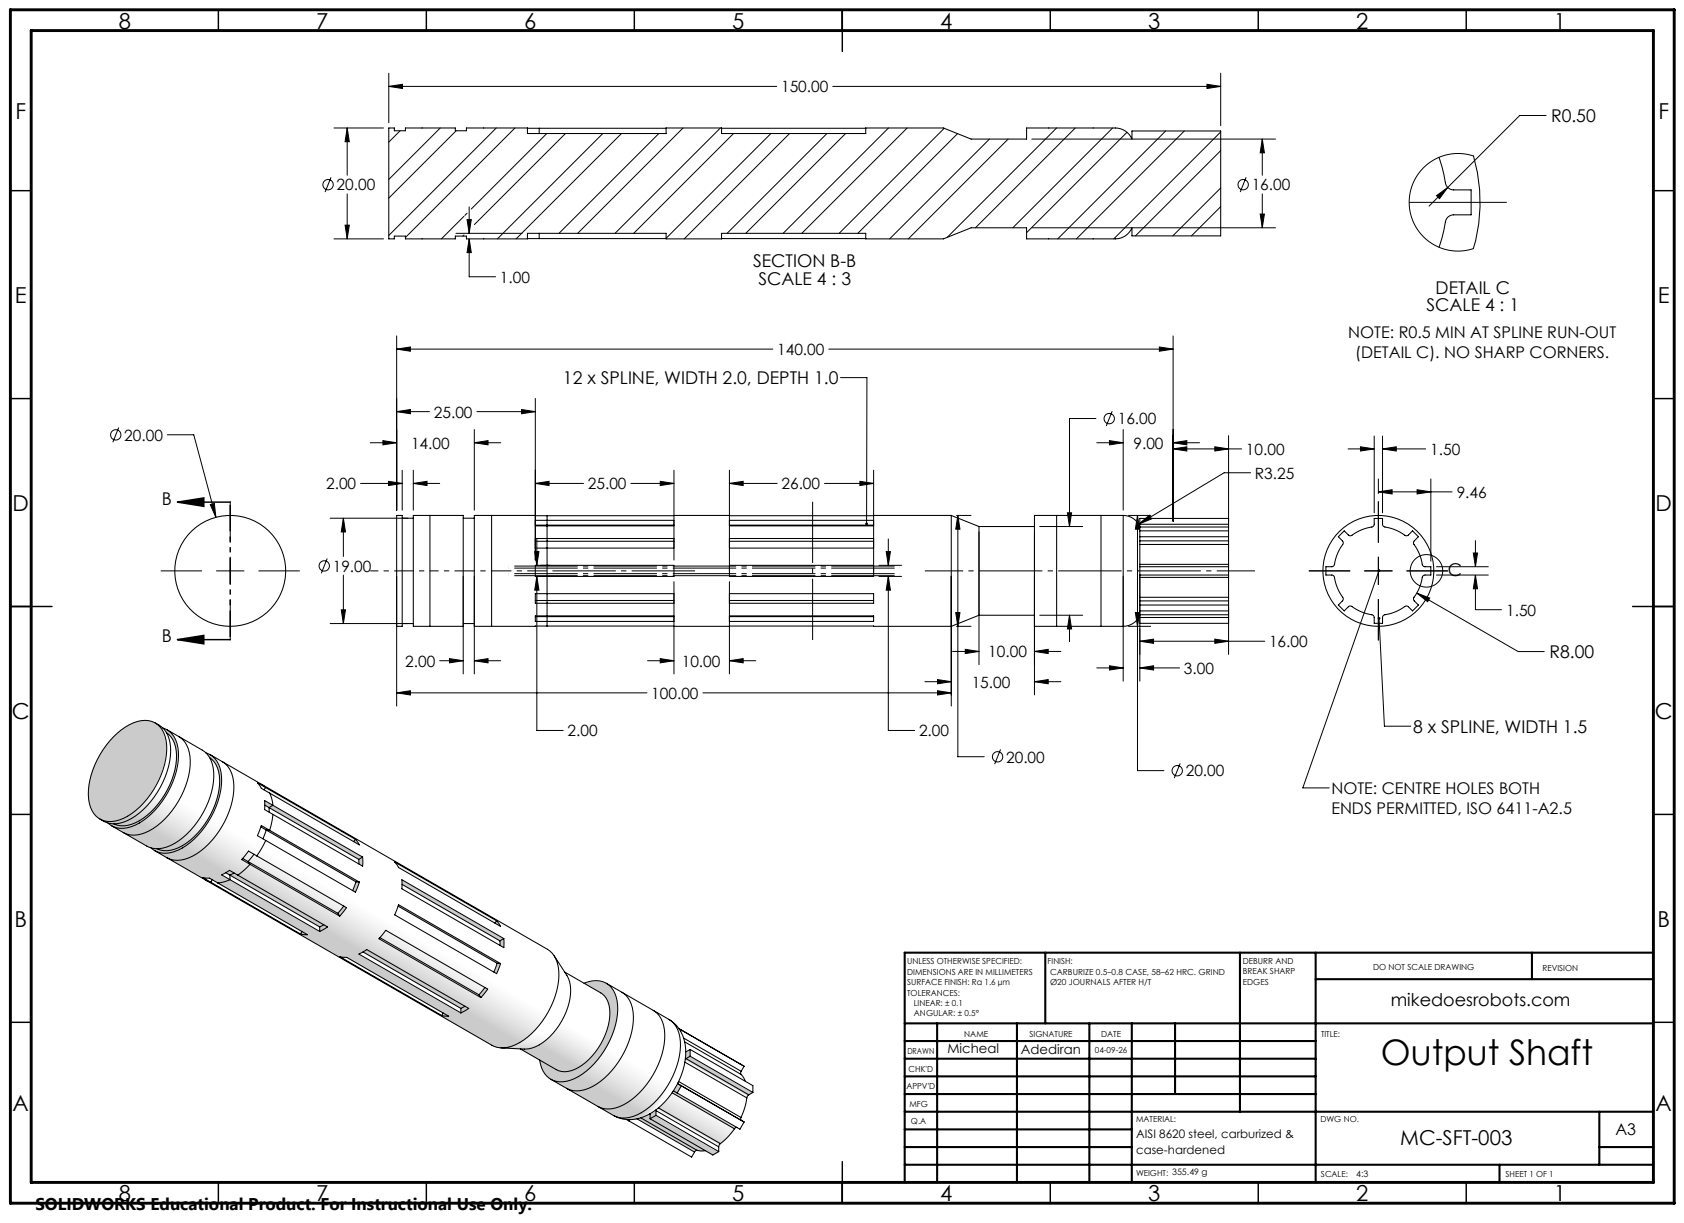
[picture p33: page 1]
8 x SPLINE, WIDTH 1.5; SECTION B-B SCALE 4 : 3; DETAIL C SCALE 4 : 1; FINISH:; DEBURR AND; BREAK SHARP; DO NOT SCALE DRAWING; REVISION; SCALE:; SHEET 1 OF 1

NOTE: R0.5 MIN AT SPLINE RUN-OUT
(DETAIL C). NO SHARP CORNERS.

12 x SPLINE, WIDTH 2.0, DEPTH 1.0

NOTE: CENTRE HOLES BOTH
ENDS PERMITTED, ISO 6411-A2.5

UNLESS OTHERWISE SPECIFIED:
DIMENSIONS ARE IN MILLIMETERS
SURFACE FINISH: Ra 1.6 µm
TOLERANCES:
LINEAR: ± 0.1
ANGULAR: ± 0.5°

CARBURIZE 0.5–0.8 CASE, 58–62 HRC. GRIND
Ø20 JOURNALS AFTER H/T

DRAWN | | Adediran | 04-09-26 | | | | Output Shaft Micheal

NAME | SIGNATURE | DATE | | | | TITLE:

CHK'D
APPV'D
MFG
Q.A | | | | MATERIAL: AISI 8620 steel, carburized & case-hardened | DWG NO. MC-SFT-003 | A3

SOLIDWORKS Educational Product. For Instructional Use Only.

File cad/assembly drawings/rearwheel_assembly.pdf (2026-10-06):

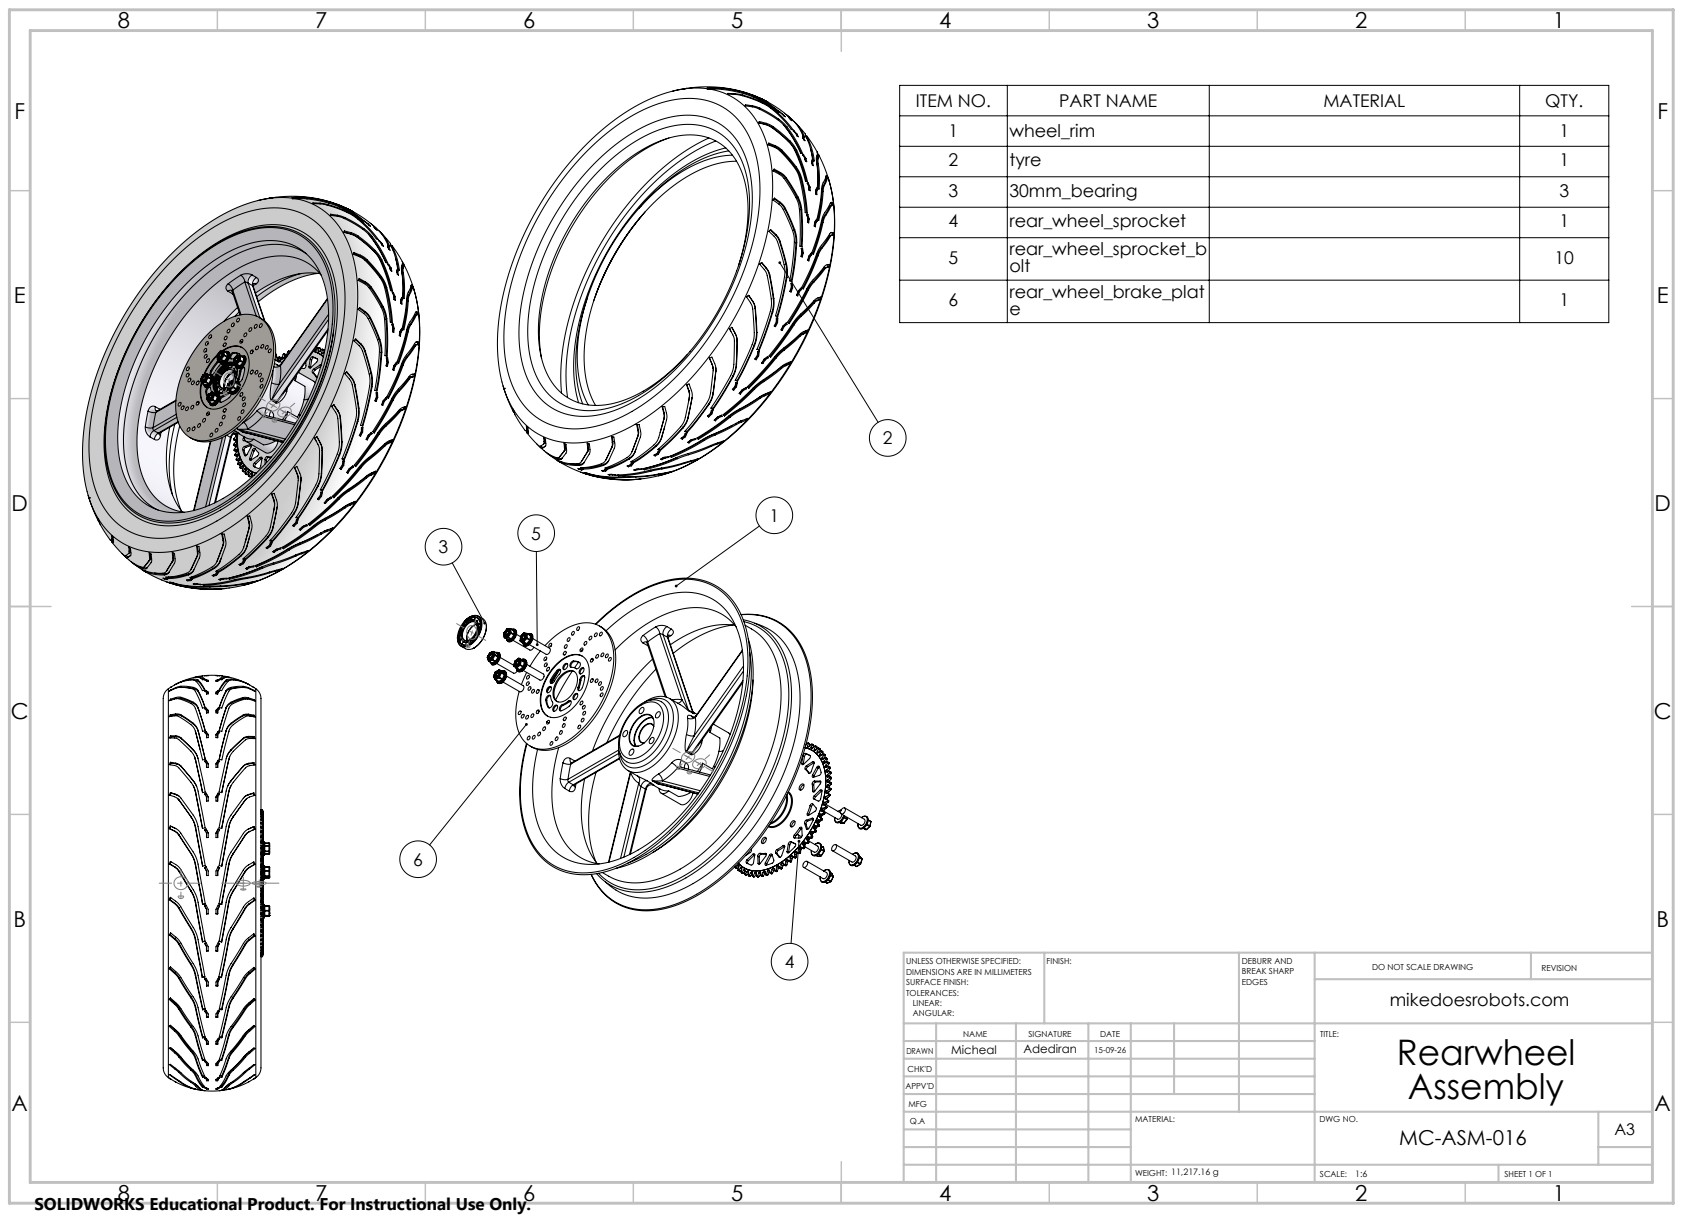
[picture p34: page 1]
FINISH:; DEBURR AND; BREAK SHARP; DO NOT SCALE DRAWING; REVISION; SCALE:; SHEET 1 OF 1

ITEM NO. | PART NAME | MATERIAL | QTY.
1 | wheel_rim | | 1
2 | tyre | | 1
3 | 30mm_bearing | | 3
4 | rear_wheel_sprocket | | 1
5 | rear_wheel_sprocket_b olt | | 10
6 | rear_wheel_brake_plat e | | 1

UNLESS OTHERWISE SPECIFIED:
DIMENSIONS ARE IN MILLIMETERS
SURFACE FINISH:
TOLERANCES:
LINEAR:
ANGULAR:

DRAWN | Micheal | Adediran | 15-09-26

NAME | SIGNATURE | DATE | | | | TITLE: Rearwheel Assembly

CHK'D
APPV'D
MFG
Q.A | | | | MATERIAL: | DWG NO. MC-ASM-016 | A3

SOLIDWORKS Educational Product. For Instructional Use Only.

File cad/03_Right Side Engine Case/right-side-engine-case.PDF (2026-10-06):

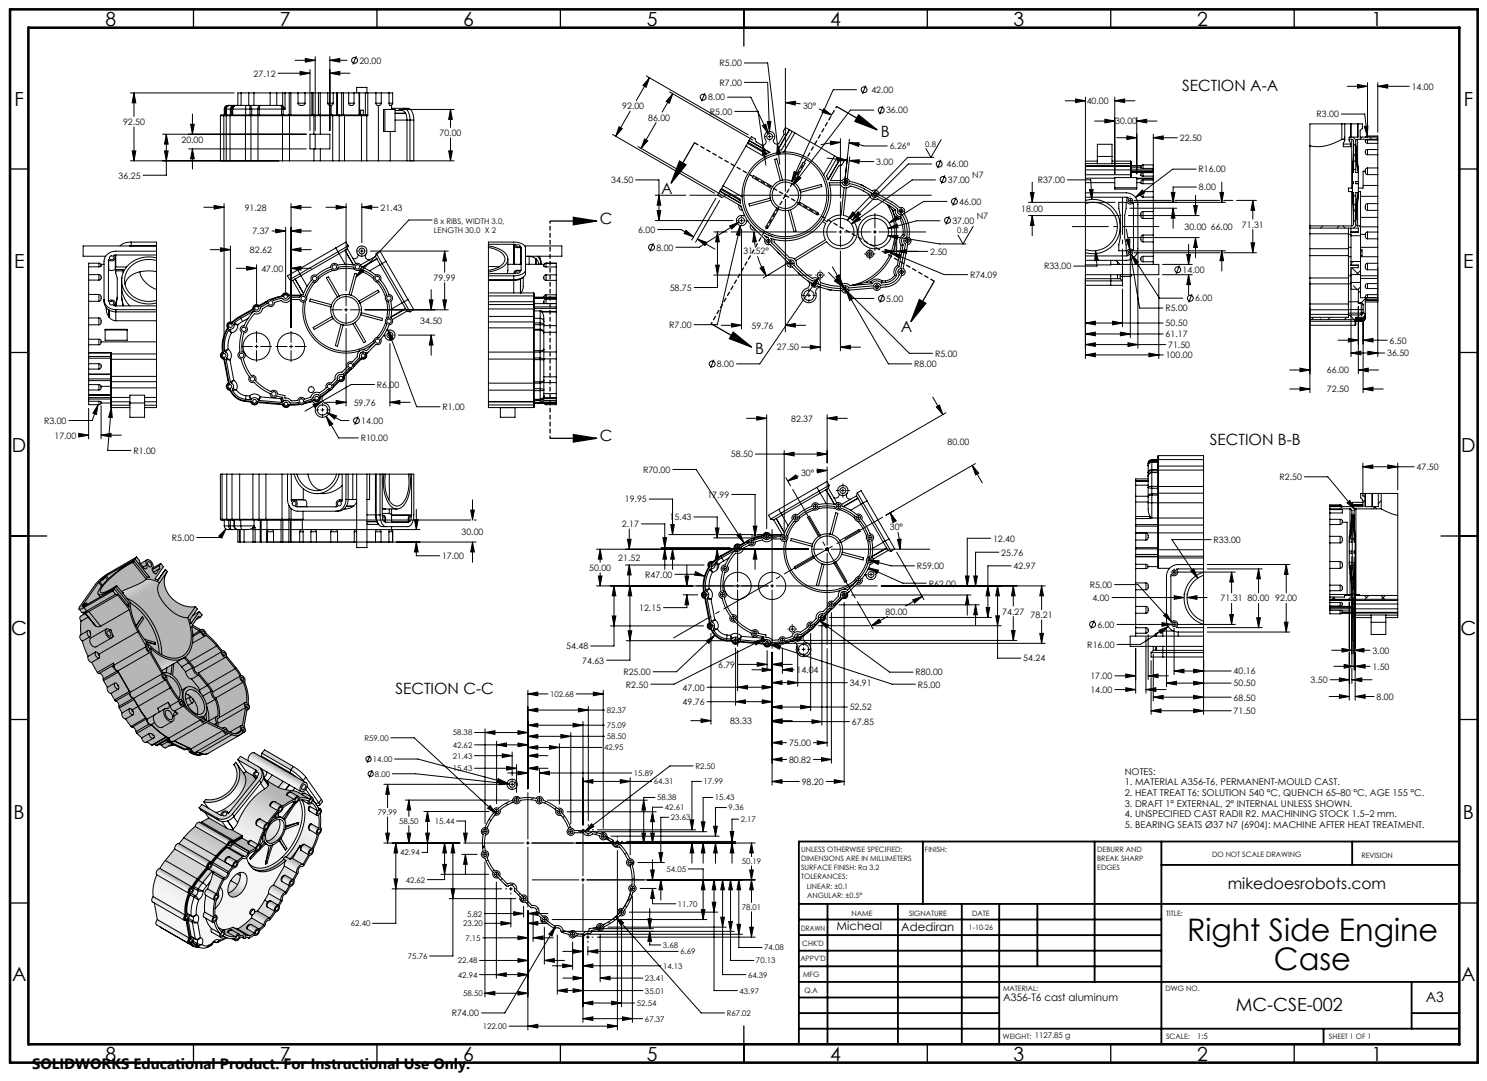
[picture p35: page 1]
8 x RIBS, WIDTH 3.0, LENGTH 30.0 X 2; SECTION A-A; SECTION B-B; SECTION C-C; FINISH:; DEBURR AND; BREAK SHARP; DO NOT SCALE DRAWING; REVISION; SCALE:; SHEET 1 OF 1

NOTES:
1. MATERIAL A356-T6, PERMANENT-MOULD CAST.
2. HEAT TREAT T6: SOLUTION 540 °C, QUENCH 65–80 °C, AGE 155 °C.
3. DRAFT 1° EXTERNAL, 2° INTERNAL UNLESS SHOWN.
4. UNSPECIFIED CAST RADII R2. MACHINING STOCK 1.5–2 mm.
5. BEARING SEATS Ø37 N7 (6904): MACHINE AFTER HEAT TREATMENT.

UNLESS OTHERWISE SPECIFIED:
DIMENSIONS ARE IN MILLIMETERS
SURFACE FINISH: Ra 3.2
TOLERANCES:
LINEAR: ±0.1
ANGULAR: ±0.5°

DRAWN | Micheal | Adediran | 1-10-26

NAME | SIGNATURE | DATE | | | | TITLE: Right Side Engine Case

CHK'D
APPV'D
MFG
Q.A | | | | MATERIAL: A356-T6 cast aluminum | DWG NO. MC-CSE-002 | A3

SOLIDWORKS Educational Product. For Instructional Use Only.

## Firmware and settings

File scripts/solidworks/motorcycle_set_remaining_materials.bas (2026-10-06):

Attribute VB_Name = "MotorcycleRemainingMaterials"
'==============================================================================
' MotorcycleRemainingMaterials - assign REAL SolidWorks materials to the parts
' that motorcycle_set_real_materials.bas (v3, 158 parts) never covered:
' bolts, bearings, spark plugs, intake/exhaust manifolds, gas tank, controller,
' stator magnets/nut, valve, piston pin, etc.
'
' Generated 2026-09-26. Same proven open -> set -> read back -> save logic as
' v3 (which logged assigned=158 failed=0).
'
' ALSO WRITES A "Mass" CUSTOM PROPERTY
'   Each part gets Mass = "SW-Mass@<file>.SLDPRT" (a live link, not a typed
'   number), so a drawing BOM can show a Mass column. With promoted
'   subassemblies those masses then show per part at the top level.
'   Set MASS_ON_ALL_PARTS = True to also add that link to EVERY part under
'   ROOT_FOLDER (the 158 from the earlier macro included) without touching
'   their materials.
'
' BEFORE YOU RUN
'   1. Close SolidWorks completely and reopen it fresh. Do not open anything.
'   2. Leave DRY_RUN = True first and check the log, then set it to False.
'
' HOW TO USE
'   Tools > Macro > New..., File > Import File... this .bas, delete the
'   auto-created boilerplate module, run Main.
'==============================================================================
Option Explicit

'--- settings ----------------------------------------------------------------
Private Const ROOT_FOLDER As String = "C:\Users\micheal\Downloads\motorcyle\frame"
Private Const LOG_FILE    As String = "remaining_materials_log.txt"

Private Const DRY_RUN As Boolean = True

' Add/refresh the "Mass" custom property on each part this macro assigns.
Private Const ADD_MASS_PROPERTY As Boolean = True

' Also add the "Mass" property to every other .SLDPRT under ROOT_FOLDER.
Private Const MASS_ON_ALL_PARTS As Boolean = False

'--- SolidWorks enums (prefixed to avoid clashing with swconst) ---------------
Private Const cDocPART          As Long = 1
Private Const cOpenSilent       As Long = 1
Private Const cSaveSilent       As Long = 1
Private Const cCustomInfoText   As Long = 30
Private Const cPropReplaceValue As Long = 2

Private Const SW_DB     As String = "SOLIDWORKS Materials"
Private Const CUSTOM_DB As String = "Custom Materials"

'--- state -------------------------------------------------------------------
Private swApp     As Object
Private mPaths()  As String
Private mDbs()    As String
Private mMats()   As String
Private mCount    As Long
Private mLog      As Integer
Private nOK As Long, nMissing As Long, nFailed As Long, nDry As Long, nNoConfig As Long
Private nMassOnly As Long


Sub Main()
    Dim i As Long

    Set swApp = Application.SldWorks
    If swApp Is Nothing Then
        MsgBox "Could not attach to SolidWorks.", vbCritical
        Exit Sub
    End If

    swApp.CloseAllDocuments True

    ReDim mPaths(0 To 100)
    ReDim mDbs(0 To 100)
    ReDim mMats(0 To 100)
    mCount = 0

    mLog = FreeFile
    Open ROOT_FOLDER & "\" & LOG_FILE For Output As #mLog
    WriteLog "MotorcycleRemainingMaterials run " & Now
    WriteLog "DRY_RUN=" & DRY_RUN & "  ADD_MASS_PROPERTY=" & ADD_MASS_PROPERTY & _
             "  MASS_ON_ALL_PARTS=" & MASS_ON_ALL_PARTS
    WriteLog String(78, "-")

    LoadRows_Fasteners
    LoadRows_Engine
    LoadRows_FrameBody
    WriteLog "queued " & mCount & " part(s)."
    WriteLog String(78, "-")

    For i = 0 To mCount - 1
        ProcessOne mPaths(i), mDbs(i), mMats(i)
    Next i

    If MASS_ON_ALL_PARTS Then
        WriteLog String(78, "-")
        WriteLog "mass-property pass over every part under " & ROOT_FOLDER
        MassWalk CreateObject("Scripting.FileSystemObject").GetFolder(ROOT_FOLDER)
    End If

    WriteLog String(78, "-")
    WriteLog "assigned=" & nOK & "  missing=" & nMissing & _
        "  failed=" & nFailed & "  no-active-config=" & nNoConfig & _
        "  skipped(dry run)=" & nDry & "  mass-only=" & nMassOnly
    Close #mLog

    MsgBox "Queued: " & mCount & vbCrLf & _
           "Assigned: " & nOK & vbCrLf & _
           "Missing on disk: " & nMissing & vbCrLf & _
           "Failed: " & nFailed & vbCrLf & _
           "No active config: " & nNoConfig & vbCrLf & _
           "Skipped (dry run): " & nDry & vbCrLf & _
           "Mass property only: " & nMassOnly & vbCrLf & vbCrLf & _
           "Log: " & ROOT_FOLDER & "\" & LOG_FILE, vbInformation, _
           "Motorcycle remaining materials"
End Sub


Private Sub ProcessOne(ByVal relPath As String, ByVal dbName As String, _
                       ByVal matName As String)
    Dim full As String, errs As Long, warns As Long
    Dim swModel As Object, swConf As Object, configName As String
    Dim verified As String

    full = ROOT_FOLDER & "\" & relPath

    If Dir(full) = "" Then
        nMissing = nMissing + 1
        WriteLog "MISSING  " & relPath
        Exit Sub
    End If

    If DRY_RUN Then
        nDry = nDry + 1
        WriteLog "DRYRUN   " & relPath & "   -> " & matName
        Exit Sub
    End If

    Set swModel = swApp.OpenDoc6(full, cDocPART, cOpenSilent, "", errs, warns)
    If swModel Is Nothing Then
        nFailed = nFailed + 1
        WriteLog "OPENFAIL " & relPath & "   err=" & errs
        Exit Sub
    End If

    Set swConf = swModel.GetActiveConfiguration
    If swConf Is Nothing Then
        nNoConfig = nNoConfig + 1
        WriteLog "NOCONFIG " & relPath
        swApp.CloseAllDocuments True
        Exit Sub
    End If
    configName = swConf.Name

'    Statement call, return value ignored - it is unusable (see v3 notes).
'    Verify by reading the material back instead.
    On Error Resume Next
    Err.Clear
    swModel.SetMaterialPropertyName2 configName, dbName, matName
    Err.Clear
    On Error GoTo 0

    verified = ReadBack(swModel, configName)

    If StrComp(Trim$(verified), Trim$(matName), vbTextCompare) <> 0 Then
        On Error Resume Next
        Err.Clear
        swModel.SetMaterialPropertyName2 "", dbName, matName
        Err.Clear
        On Error GoTo 0
        verified = ReadBack(swModel, configName)
    End If

    If StrComp(Trim$(verified), Trim$(matName), vbTextCompare) <> 0 Then
        nFailed = nFailed + 1
        WriteLog "NOTAPPLIED " & relPath & "   wanted=[" & matName & _
            "]  got=[" & verified & "]"
        swApp.CloseAllDocuments True
        Exit Sub
    End If

    If ADD_MASS_PROPERTY Then SetMassProperty swModel, full

    errs = 0: warns = 0
    swModel.Save3 cSaveSilent, errs, warns
    If errs <> 0 Then
        nFailed = nFailed + 1
        WriteLog "SAVEFAIL " & relPath & "   err=" & errs & "   (material applied but NOT saved)"
        swApp.CloseAllDocuments True
        Exit Sub
    End If

    nOK = nOK + 1
    WriteLog "SAVED    " & relPath & "   -> " & verified
    swApp.CloseAllDocuments True
End Sub


' Links a file-level "Mass" property to the mass SolidWorks calculates.
Private Sub SetMassProperty(ByVal swModel As Object, ByVal fullPath As String)
    Dim cpm As Object, fileName As String
    fileName = Mid$(fullPath, InStrRev(fullPath, "\") + 1)
    Set cpm = swModel.Extension.CustomPropertyManager("")
    cpm.Add3 "Mass", cCustomInfoText, """SW-Mass@" & fileName & """", cPropReplaceValue
End Sub


' Adds the Mass property to every part under a folder, materials untouched.
Private Sub MassWalk(ByVal fld As Object)
    Dim f As Object, subFld As Object, rel As String
    Dim swModel As Object, errs As Long, warns As Long

    For Each f In fld.Files
        If LCase$(Right$(f.Name, 7)) = ".sldprt" And Left$(f.Name, 2) <> "~$" Then
            rel = Mid$(f.Path, Len(ROOT_FOLDER) + 2)
            If DRY_RUN Then
                WriteLog "DRYMASS  " & rel
            Else
                Set swModel = swApp.OpenDoc6(f.Path, cDocPART, cOpenSilent, "", errs, warns)
                If swModel Is Nothing Then
                    WriteLog "MASSOPENFAIL " & rel & "   err=" & errs
                Else
                    SetMassProperty swModel, f.Path
                    errs = 0: warns = 0
                    swModel.Save3 cSaveSilent, errs, warns
                    If errs <> 0 Then
                        WriteLog "MASSSAVEFAIL " & rel & "   err=" & errs
                    Else
                        nMassOnly = nMassOnly + 1
                        WriteLog "MASS     " & rel
                    End If
                    swApp.CloseAllDocuments True
                End If
            End If
        End If
    Next f

    For Each subFld In fld.SubFolders
        MassWalk subFld
    Next subFld
End Sub


Private Function ReadBack(ByVal swModel As Object, ByVal cfg As String) As String
    Dim db As String, m As String
    db = ""
    On Error Resume Next
    Err.Clear
    m = swModel.GetMaterialPropertyName2(cfg, db)
    If Err.Number <> 0 Then m = "<read error " & Err.Number & ">"
    Err.Clear
    On Error GoTo 0
    ReadBack = m
End Function


Private Sub AddRow(ByVal relPath As String, ByVal dbPath As String, _
                   ByVal matName As String)
    If mCount > UBound(mPaths) Then
        ReDim Preserve mPaths(0 To mCount + 50)
        ReDim Preserve mDbs(0 To mCount + 50)
        ReDim Preserve mMats(0 To mCount + 50)
    End If
    mPaths(mCount) = relPath
    mDbs(mCount) = dbPath
    mMats(mCount) = matName
    mCount = mCount + 1
End Sub


Private Sub WriteLog(ByVal s As String)
    Print #mLog, s
    Debug.Print s
End Sub


'==============================================================================
' DATA - part, material database, exact material name
'==============================================================================

' Bolts, nuts, screws: 4140 Q&T, same as piston_bolt in the first macro
' (roughly property class 10.9).
Private Sub LoadRows_Fasteners()
    Const M As String = "AISI 4140 Steel, quenched & tempered"
    AddRow "04_Clutch Hub Parts\clutch_hub_pressure_bolt.SLDPRT", CUSTOM_DB, M
    AddRow "09_Stator Parts\stator_nut.SLDPRT", CUSTOM_DB, M
    AddRow "20_Bolts - Various\bolt_cylinder_section_mced.SLDPRT", CUSTOM_DB, M
    AddRow "20_Bolts - Various\bolt_engine_case_l_to_c_mced.SLDPRT", CUSTOM_DB, M
    AddRow "20_Bolts - Various\bolt_engine_case_l_to_r_mced.SLDPRT", CUSTOM_DB, M
    AddRow "20_Bolts - Various\bolt_front_wheel_frame_clamp_mced.SLDPRT", CUSTOM_DB, M
    AddRow "20_Bolts - Various\bolt_head_case_mced.SLDPRT", CUSTOM_DB, M
    AddRow "20_Bolts - Various\bolt_large_engine_case_l_to_r_mced.SLDPRT", CUSTOM_DB, M
    AddRow "20_Bolts - Various\frame_engine_bolt.SLDPRT", CUSTOM_DB, M
    AddRow "20_Bolts - Various\smallpressurebolt-4mm.SLDPRT", CUSTOM_DB, M
    AddRow "20_Bolts - Various\testscrew.SLDPRT", CUSTOM_DB, M
    AddRow "23_Rear Wheel Parts\rear_wheel_frame_as_bolt.SLDPRT", CUSTOM_DB, M
    AddRow "23_Rear Wheel Parts\rear_wheel_frame_shaft_bolt.SLDPRT", CUSTOM_DB, M
    AddRow "23_Rear Wheel Parts\rear_wheel_sprocket_bolt.SLDPRT", CUSTOM_DB, M
    AddRow "24_Front Wheel Parts\front_wheel_frame_shaft_bolt.SLDPRT", CUSTOM_DB, M
    AddRow "24_Front Wheel Parts\front_wheel_frame_shaft_boltdd.SLDPRT", CUSTOM_DB, M
    AddRow "24_Front Wheel Parts\front_wheel_side_pipe_top_bolt.SLDPRT", CUSTOM_DB, M
    AddRow "30_Shock Absorber Parts\shock_absorber_pin_a_bolt.SLDPRT", CUSTOM_DB, M
End Sub

Private Sub LoadRows_Engine()
'    Ball bearings: Chrome Stainless Steel is the library's closest to 52100.
    AddRow "19_20mm and 30mm Ball Bearings\20mm_bearing_balls_mced.SLDPRT", SW_DB, "Chrome Stainless Steel"
    AddRow "19_20mm and 30mm Ball Bearings\20mm_bearing_inner_ring_mced.SLDPRT", SW_DB, "Chrome Stainless Steel"
    AddRow "19_20mm and 30mm Ball Bearings\20mm_bearing_outer_ring_mced.SLDPRT", SW_DB, "Chrome Stainless Steel"
    AddRow "19_20mm and 30mm Ball Bearings\30mm_bearing_balls_mced.SLDPRT", SW_DB, "Chrome Stainless Steel"
    AddRow "19_20mm and 30mm Ball Bearings\30mm_bearing_inner_ring_mced.SLDPRT", SW_DB, "Chrome Stainless Steel"
    AddRow "19_20mm and 30mm Ball Bearings\30mm_bearing_outer_ring_mced.SLDPRT", SW_DB, "Chrome Stainless Steel"

'    Spark plug is one body; the steel shell dominates its mass.
    AddRow "14-Spark Plugs\Spark Plug.SLDPRT", SW_DB, "AISI 1020 Steel, Cold Rolled"
    AddRow "14-Spark Plugs\Spark Plug2.SLDPRT", SW_DB, "AISI 1020 Steel, Cold Rolled"

    AddRow "13_Valve Section Engine Case and Valve Parts\valve.SLDPRT", SW_DB, "Chrome Stainless Steel"
    AddRow "16_Piston Parts\piston_pin.SLDPRT", CUSTOM_DB, "AISI 8620 Steel, carburized"

'    No NdFeB/ferrite in the library; Cast Alloy Steel (7.3 g/cc) is close
'    to NdFeB density (~7.5 g/cc), so the mass comes out right.
    AddRow "09_Stator Parts\stator_magnets.SLDPRT", SW_DB, "Cast Alloy Steel"

'    Intake manifold: cast aluminium like the engine cases; the connector is
'    the rubber boot to the carb/filter. Exhaust manifold: 304 like the muffler.
    AddRow "Assembly\airintake_mandifold.SLDPRT", CUSTOM_DB, "A356-T6 cast aluminum alloy"
    AddRow "Assembly\airintake_connector.SLDPRT", SW_DB, "Natural Rubber"
    AddRow "Assembly\exhaust_mandifold.SLDPRT", SW_DB, "AISI 304"
End Sub

Private Sub LoadRows_FrameBody()
    AddRow "01_Introduction - Motorcycle Frame\frame_chassis.SLDPRT", SW_DB, "AISI 4130 Steel, normalized at 870C"
    AddRow "01_Introduction - Motorcycle Frame\rearbodysection.sldprt", SW_DB, "ABS"
    AddRow "23_Rear Wheel Parts\rear_wheel_frame_old.SLDPRT", SW_DB, "AISI 4130 Steel, normalized at 870C"

    AddRow "31_Handlebar and Hand Brake Parts\connectingcable.SLDPRT", SW_DB, "PVC 0.007 Plasticized"
    AddRow "31_Handlebar and Hand Brake Parts\connectingcable2.SLDPRT", SW_DB, "PVC 0.007 Plasticized"

'    Body panels follow the first macro's ABS convention.
    AddRow "body\freeformmodelling-creo\gastank.SLDPRT", SW_DB, "ABS"
    AddRow "body\freeformmodelling-creo\gastanklift.SLDPRT", SW_DB, "ABS"
    AddRow "body\freeformmodelling-creo\gastankv2.SLDPRT", SW_DB, "ABS"
    AddRow "body\freeformmodelling-creo\rearbody123.SLDPRT", SW_DB, "ABS"
    AddRow "body\freeformmodelling-creo\seater221.SLDPRT", SW_DB, "ABS"
    AddRow "body\seatrim.SLDPRT", SW_DB, "ABS"

    AddRow "controler\case.SLDPRT", SW_DB, "ABS"
    AddRow "controler\caseback.SLDPRT", SW_DB, "ABS"
    AddRow "controler\button1.SLDPRT", SW_DB, "ABS"
    AddRow "controler\button2.SLDPRT", SW_DB, "ABS"
    AddRow "controler\button3.SLDPRT", SW_DB, "ABS"
    AddRow "controler\buttonw.SLDPRT", SW_DB, "ABS"
    AddRow "controler\leds.SLDPRT", SW_DB, "PC High Viscosity"

'    Not assigned - unclear what these are. Fill in and uncomment if needed:
'    AddRow "99_Unsorted - Review\lswugpart2.SLDPRT", SW_DB, "?"
'    AddRow "99_Unsorted - Review\part.SLDPRT", SW_DB, "?"
'    AddRow "assembly drawings\Part1.SLDPRT", SW_DB, "?"
End Sub

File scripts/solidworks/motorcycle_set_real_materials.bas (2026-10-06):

Attribute VB_Name = "MotorcycleRealMaterials"
'==============================================================================
' MotorcycleRealMaterials v2 - assign REAL SolidWorks materials to 158 parts
'
' Generated 2026-09-19
'
' WHAT CHANGED IN v3 - THE ACTUAL BUG
'   SetMaterialPropertyName2 applies the material correctly but returns
'   no usable value. Reading it as a Boolean gives False even when it
'   worked, so every previous run treated success as failure and closed
'   the part WITHOUT SAVING. That is why materials appeared during the
'   run and were gone after a restart. v3 ignores the return value,
'   verifies by reading the material back, then saves.
'
' EARLIER CHANGES
'   1. Main() now force-closes EVERY open document (including any open
'      assembly) before touching a single part. v1 left that to you, and
'      an assembly left open in the background was silently reloading and
'      snapshotting parts mid-run, then overwriting finished work when it
'      got saved later. This removes that risk at the source.
'   2. Each part now tries THREE ways of calling the material-assignment
'      API in sequence (documented, config='', config object direct) and
'      logs exactly which one worked - or all three, with the real VBA
'      error text, if none did. v1 only tried one and printed a guess.
'
' WHAT THIS WRITES
'   Real SolidWorks material assignment (not the text custom property -
'   that part is already done and untouched by this macro). After this
'   runs: FeatureManager tree shows the real material instead of <not
'   specified>, mass/density/appearance are real.
'
' BEFORE YOU RUN
'   1. Close SolidWorks completely and reopen it fresh. Don't open the
'      assembly, don't open any part - let the macro do all opening.
'   2. Leave DRY_RUN = True first. It closes other docs and opens nothing
'      of its own, just writes the log.
'
' AFTER IT FINISHES
'   Verify by opening a couple of PART files directly - not the assembly.
'   If those are correct, the fix worked at the source and the assembly
'   will simply display them correctly next time you open it. You should
'   not need to open or save the assembly at all for this to stick.
'
' HOW TO USE
'   Tools > Macro > New..., then in the VBA editor File > Import File... and
'   pick this .bas. DELETE the boilerplate module SolidWorks auto-creates -
'   its empty Sub main collides with this one. Then run Main.
'==============================================================================
Option Explicit

'--- settings ----------------------------------------------------------------
Private Const ROOT_FOLDER As String = "C:\Users\micheal\Downloads\motorcyle\frame"
Private Const LOG_FILE    As String = "real_materials_log.txt"

' True = report only. Still closes other open documents, opens none of
' its own. RUN THIS FIRST.
Private Const DRY_RUN As Boolean = True

' Save each document after editing.
Private Const SAVE_AFTER As Boolean = True

'--- SolidWorks enums (prefixed to avoid clashing with swconst) ---------------
Private Const cDocPART    As Long = 1
Private Const cOpenSilent As Long = 1
Private Const cSaveSilent As Long = 1

'--- state -------------------------------------------------------------------
Private swApp     As Object
Private mPaths()  As String
Private mDbs()    As String
Private mMats()   As String
Private mCount    As Long
Private mLog      As Integer
Private nOK As Long, nMissing As Long, nFailed As Long, nDry As Long, nNoConfig As Long


Sub Main()
    Dim i As Long
    Dim openDocs As Variant, d As Object

    Set swApp = Application.SldWorks
    If swApp Is Nothing Then
        MsgBox "Could not attach to SolidWorks.", vbCritical
        Exit Sub
    End If

'    Force-close everything currently open, including any assembly.
'    This is the fix for materials reverting: an assembly left open in
'    the background was reloading and re-snapshotting parts mid-run.
    swApp.CloseAllDocuments True

    ReDim mPaths(0 To 300)
    ReDim mDbs(0 To 300)
    ReDim mMats(0 To 300)
    mCount = 0

    mLog = FreeFile
    Open ROOT_FOLDER & "\" & LOG_FILE For Output As #mLog
    WriteLog "MotorcycleRealMaterials v2 run " & Now
    WriteLog "DRY_RUN=" & DRY_RUN
    WriteLog "closed all open documents before starting"
    WriteLog String(78, "-")

    LoadRows_01
    LoadRows_02
    LoadRows_03
    LoadRows_04
    WriteLog "queued " & mCount & " part(s)."
    WriteLog String(78, "-")

    For i = 0 To mCount - 1
        ProcessOne mPaths(i), mDbs(i), mMats(i)
    Next i

    WriteLog String(78, "-")
    WriteLog "assigned=" & nOK & "  missing=" & nMissing & _
        "  failed=" & nFailed & "  no-active-config=" & nNoConfig & _
        "  skipped(dry run)=" & nDry
    Close #mLog

    MsgBox "Queued: " & mCount & vbCrLf & _
           "Assigned: " & nOK & vbCrLf & _
           "Missing on disk: " & nMissing & vbCrLf & _
           "Failed: " & nFailed & vbCrLf & _
           "No active config: " & nNoConfig & vbCrLf & _
           "Skipped (dry run): " & nDry & vbCrLf & vbCrLf & _
           "Log: " & ROOT_FOLDER & "\" & LOG_FILE, vbInformation, _
           "Motorcycle real materials v2"
End Sub


Private Sub ProcessOne(ByVal relPath As String, ByVal dbName As String, _
                       ByVal matName As String)
    Dim full As String, errs As Long, warns As Long
    Dim swModel As Object, swConf As Object, configName As String
    Dim verified As String

    full = ROOT_FOLDER & "\" & relPath

    If Dir(full) = "" Then
        nMissing = nMissing + 1
        WriteLog "MISSING  " & relPath
        Exit Sub
    End If

    If DRY_RUN Then
        nDry = nDry + 1
        WriteLog "DRYRUN   " & relPath & "   -> " & matName
        Exit Sub
    End If

    Set swModel = swApp.OpenDoc6(full, cDocPART, cOpenSilent, "", errs, warns)
    If swModel Is Nothing Then
        nFailed = nFailed + 1
        WriteLog "OPENFAIL " & relPath & "   err=" & errs
        Exit Sub
    End If

    Set swConf = swModel.GetActiveConfiguration
    If swConf Is Nothing Then
        nNoConfig = nNoConfig + 1
        WriteLog "NOCONFIG " & relPath
        swApp.CloseAllDocuments True
        Exit Sub
    End If
    configName = swConf.Name

'    Call it as a STATEMENT, not a function. SetMaterialPropertyName2
'    does the work but gives back no usable return value - reading it as
'    Boolean yields False even on success, which is what made every
'    previous run bail out before saving. We ignore the result entirely
'    and verify by reading the material back instead.
    On Error Resume Next
    Err.Clear
    swModel.SetMaterialPropertyName2 configName, dbName, matName
    Err.Clear
    On Error GoTo 0

    verified = ReadBack(swModel, configName)
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

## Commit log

2026-10-06 Add Café Racer Concept: SolidWorks CAD, FEA, renders, film and scripts
    [20mm_bearing.SLDASM, 20mm_bearing_balls_mced.SLDPRT, 20mm_bearing_inner_ring_mced.SLDPRT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]
2026-10-06 Add front wing ground-effect CFD study
    Geometry, Fluent case files, lift and drag histories and result plots
    for the 11 ride-height sweep, with a README giving the set-up and the
    final coefficients for each case.
    [downforce_coefficient_vs_ride_height.csv, efficiency_vs_ride_height.csv, wing_hc0.06.dxf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]
2026-10-06 Move front wing CFD study to its own repository
    It is a separate project from the café racer and now lives at
    https://github.com/brickflows/front-wing-ground-effect.
    This reverts commit f2187bc.
    [downforce_coefficient_vs_ride_height.csv, efficiency_vs_ride_height.csv, wing_hc0.06.dxf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]
